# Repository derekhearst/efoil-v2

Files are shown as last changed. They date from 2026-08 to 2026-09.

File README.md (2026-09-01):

# eFoil V2

A DIY electric hydrofoil board, generated from a parametric Blender model that
also emits its own CNC drawings, cutting patterns, glass ply templates and
bill of materials. Change a parameter, re-run, and every downstream document
follows.

**V1 is built and riding.** V2 is the board this repo is about: a full model
with `FAILS: ['none']` on every check, a BOM where 131 of 135 purchasable
lines link to a real listing, and a machining plan that fits a specific
router in a specific shop.

---

## The one rule

**Nothing in `cnc/`, `print/`, `docs/bom.md` or `docs/shopping.md` is written
by hand.** They are generated from `model/*.py`. Editing them guarantees
drift, and drift in a cut list is a part you machine twice.

`model/report.json` is the contract between the scripts: `blender_board.py`
writes it, everything else reads it. `bom.py` refuses to run if it is stale.

---

## Regenerate everything

```bash
blender -b --factory-startup --python-expr "exec(open(r'C:/Users/derek/Development/eFoil/model/blender_board.py').read())"
```

That rewrites `model/efoil_v2.blend`, `model/efoil_v2_hull.stl` and
`model/report.json`, and prints the full check report. **If you have the
.blend open in the GUI, reopen it afterwards** — otherwise you are looking at
geometry that has already been fixed.

Then, in any order:

```bash
python model/cnc_drawings.py      # DXF part drawings + cnc/cut-list.md
python model/bom.py               # docs/bom.md + docs/shopping.md
python model/glass_templates.py   # developed glass ply outlines, DXF + printable HTML
```

```bash
blender -b --factory-startup --python model/print_miniature.py
```

Miniatures are exported at an explicit scale — scene units are metres and the
board is 1.4 units long, so a plain STL export reads as **1.4 mm** in a
slicer. Each file arrives at the size in its own filename.

### The build animation

```bash
blender -b model/efoil_v2.blend --python model/animate_build.py -- --res 1600
```

Two minutes covering the whole build in the order
[fabrication.md](docs/fabrication.md) gives it: glue-up, the CNC setups with
the router actually removing material, the flip, bonding, hardpoints, layup,
pack, module, install, deck pad, foil. Lands in `renders/build.mp4`, which is
**gitignored like the rest of `renders/`** — regenerate it, do not commit it.

Add `--stills` for one PNG per shot (about 15 seconds, and the way to check
choreography), `--shot NAME` for one shot, or `--dry` to print the shot list
and render nothing.

The router is not faked. Waste is built as
`slab − ((slab − part) ∩ swept)`, so the stock starts **solid** and the
finished surface is uncovered exactly where the tool has already been; the
cutter's Z is raycast against the real machined geometry rather than dropped
at a guessed height. Get that construction backwards — waste as `slab − part`,
which is the obvious one — and the finished planform is on screen before the
tool has touched anything.

---

## Layout

```
model/       the parametric model and every generator that reads it
cnc/         generated DXF drawings + cut list        (regenerate, never edit)
docs/        V2 documentation - see below
docs/v1/     V1 as-built, kept for reference only     (see "V1 archive")
print/       print-ready miniature STLs               (regenerate, never edit)
snapshots/   dated .blend captures of past shape decisions
```

Not in the repo: `renders/` (173 MB of build output) and `reference/`
(manufacturer marketing imagery used to fit the hull — not ours to
redistribute).

---

## V2 documentation

Four documents, three of them generated. Start with the build guide.

| Doc | What it covers |
|---|---|
| **[fabrication.md](docs/fabrication.md)** | **The build guide.** Every step in order, what blocks on what, what runs in parallel, and the exact BOM lines each step consumes |
| [cut-list.md](cnc/cut-list.md) | *Generated.* Every flat part, the four core pieces, the milling table, and the deck-pad cutting pattern |
| [bom.md](docs/bom.md) | *Generated.* Every line, linked to the listing its price came from, with per-line confidence |
| [shopping.md](docs/shopping.md) | *Generated.* The same spend grouped by supplier — the order you actually place orders in |
| [shape-research.md](docs/shape-research.md) | Traced production boards and the shape law fitted from them |

The build guide quotes BOM item names verbatim, and
`python model/check_build_guide.py` verifies every one still exists - and
now every bolded figure in this file and in the guide against `report.json`
and `bom_stats.json`. 133 of 135 purchasable lines are claimed by a step; the
rest are contingency tools.

---

## Key numbers

| | V1 (built) | V2 (current model) |
|---|---|---|
| Dimensions | 1600 × 600 × 153 mm | 1400 × 560 × 143.7 mm |
| Sealed displacement | 96.6 L | 79.0 L |
| Board mass | 25–30 kg | 23.6 kg |
| Board reserve, alone | — | +55.4 kg |
| With an 86 kg rider | — | **-30.6 kg — a sinker at rest** |
| Pack | 14S9P, 2,268 Wh | 16S8P, 2,304 Wh, 9.22 kg, 397 × 188 × 78 |
| Cavity | 660 × 280 × 115 mm | 512 × 323 × 86 mm |
| Electronics | 2 sealed boxes | 1 removable module: printed ASA walls on a 5052 floor, **outward** lid flange |
| Mast plate | — | 6061-**T651**, 12.7 mm, **M6** tapped, 1.44× margin |
| Hatch | — | 12 × M5 into captive nuts printed into an ASA rim ring |
| Core splits | — | vertical at 1030 mm (bed length), horizontal at 101.6 mm (gantry) |
| Machining | — | 4 pieces, 5 setups, 1 flip, no cradle |
| Deck pad | — | 3 pieces of 5.8 mm EVA, one sheet does both boards |
| Cost | ~$3,900 spent | **$4,046/board**, 90% verified |

The board is a **sinker** — 79.0 L will not float a rider standing still.
That is a consequence of narrowing to 560 mm, but note it has moved twice:
an earlier revision of this README claimed "+12.0 kg — it floats the rider"
from when displacement was 114 L, and the pack-height correction has since
given 5 kg of it back. If floating at rest matters to you, that is the number
to argue with.

---

## Open questions

Ordered by what can actually stop the build.

1. **Will the makerspace allow EPS — and cured fibreglass — on the CNC?**
   Unanswered, and it is now two materials on one phone call. It is a
   woodworking shop with no published material policy, and this is the one
   that can stop the booking outright. Maker Shop Boise, (208) 254-6151.
   EPS gates the core; **glass gates machining the two laminated lids**, and
   if the answer there is no, the MDF masters do them at home instead.
2. **Can the lids be laid up inside the CNC month?** The lids are machined on
   a *second* visit, which means the vacuum rig has to be working about three
   weeks earlier than the build order otherwise needs it. Eight visits are
   allowed in the month, so the visit is not the problem — the schedule is.
   If it slips: a **$99 day pass**, or the masters.
3. ~~**Cutter reach.**~~ **Closed.** The deepest pocket is the cavity's lower
   half at **71.6 mm** and the Freud O-flute cuts **31.8 mm**, which is where
   this question came from — but roughing never needed the reach (Z-level
   passes put the shank in open air) and the BOM has carried a **76.2 mm**
   wall-finish spiral for the one pass that does. The check was asking the
   roughing bit.
4. ~~**Wire bay stops at 68 mm.**~~ **Closed — it is 75.** The check that
   refused 75 was the in-build rim-segment volume test, the one later shown to
   report 53% of a ring that measures 99.96% in the saved file. It was
   measuring the booleans wrong, not the geometry. That test is demoted, and
   the bay is the 75 mm Derek asked for in the first place.
5. **Gong import duty.** Shipping is measured ($268.63 for two foils, from
   their checkout), but US customs is not. It arrives later as a courier
   invoice. Budget ~$210 if a 15% rate holds; the BOM carries it at zero so it
   is never mistaken for a verified figure.
6. ~~**Sinker at rest.**~~ **Closed — accepted.** 79 L will not float a
   rider standing still, and that is the board Derek wants.
7. ~~**V1's reed-switch kill system.**~~ **Closed — not doing it.** Derek's
   call on his own board. Worth recording what the item actually said: it was
   scoped *"required before any beginner rides that board"*, so it is about
   lending V1 out rather than about riding it himself. If someone else ever
   takes it out, this reopens.
8. **Measure the Gong top plate — thickness first, then its four clearance
   holes.** Two numbers, one part, and Derek already owns it (he cut its wire
   slot).

   **7a — the THICKNESS.** ~~Assumed at 20.0 mm.~~ **MEASURED: 12 mm, and
   countersunk.** That answered a question the model could not ask itself —
   `MAST_HEAD_T` had called itself *derived*, from `30 − INSERT_L`, which is
   our own tap depth, so it could only ever agree with us. The real number
   says **Gong's supplied M6 × 30 cannot be used**: a countersunk length is
   measured over the head, so it protrudes 18 mm below their plate against
   our 10 mm tap and **bottoms out by 8 mm** — torquing up tight with
   near-zero clamp on the joint carrying the whole rig.

   Not Gong's error. Those screws ship with **four M6 brass square nuts** —
   track hardware for a US box, where the length is meant to run past a plate
   and pick up a nut. We tap a plate instead, so their length was never ours.
   The board now buys **M6 × 22 A4-70 countersunk (DIN7991)**: 10 mm engaged,
   1.67 × D, 1.42× the bolt, 2.7 mm of blind alu. **The plate was right all
   along — the screws were wrong.** Still unmeasured on their part: the
   **countersink angle**, assumed 90°.

   **7b — the four clearance holes.** `MAST_CLEAR_D` is a guess at 7.0 mm and
   it sets the *entire* positional budget for our four tapped holes — at 7.0
   that budget is 0.25 mm, which is what makes it a machine-shop part rather
   than a drill-press one. A wider hole relaxes it; a tighter one may make it
   unbuildable by hand at all.
9. **Where the mast's wire slot sits relative to the chord.** `CONDUIT_X_OFF`
   is 0, i.e. the conduit is assumed to be on the mast's centreline, and that
   is unverified. If it is not, the conduit and the plate's Ø30.8 bore are in
   the wrong place — and that bore is drilled and reamed into the one part
   that has to go to a machine shop.
10. **`GUIDE_OFF` — the seal groove template's bushing offset.** Template 14's
   path is drawn **5.0 mm** outboard of the groove, which is
   `(bushing OD − cutter OD) / 2` for a bushing nobody has measured. It is
   the one number on that part that comes from the *tool* rather than the
   design, and if it is wrong the groove lands off by exactly the error — in
   the sealing land, on the joint that must not leak. **Measure it on the
   P601 before the template is cut.** It cannot come off the rotary tool: the
   TVM01 has no router base to mount a bushing to.
11. **The charge port's flange pitch, and whether a screw cap ships with it.**
   `CHG_BOLT_PITCH` is 22 mm on a two-hole SP17 flange, and no drawing has
   ever been found for it — the four-on-a-20-mm-square pattern belongs to the
   EW-LP16, a different connector. These holes go into a **printed** wall, so
   order the connector early and measure it before the module shell prints at
   step 3. The cap matters just as much: it is the entire reason this
   connector was chosen over the LP16's nicer one-touch latch, and Renhotec
   list SP17 sealing caps as *available*, which is not *included*.
12. ~~**The module vent is the next barrier down.**~~ **Closed for water.**
    It was a $9.95 no-name "IP68 nylon breather", and IP68 with no stated
    depth or duration is a marketing string, not a rating. Now a **GORE
    PolyVent Stainless, M12 × 1.5, 316L** — tested to IEC 60529 at 2 m for
    1 hour, IP69K to ISO 20653, salt fog, UL 94 VTM-0 membrane, laser-marked
    for traceability. Against the **62.2 mm** of head this cavity can ever
    put on it that is **32×**, so it goes from the module's weakest opening
    to its strongest. Sized on Gore's own table: 1.6 L/min covers a 20 L
    enclosure and the module has ~3.3 L of free air, 6× over.
13. ~~**Nothing relieves a cell venting.**~~ **Answered, and better than
    feared.** The vent is still not relief — it passes **1.6 L/min** against
    the ~12 a runaway cell wants — but the box was never a pressure vessel
    either. Both lids are hard-stop bolted joints, and a bolted joint
    separates, dumps and re-seats: the **module lets go at 0.81 bar**, the
    **hatch at 0.87**. Both are ~7× the 0.11 bar a hot box makes going into
    cold water, so neither opens in service, and both are far under anything
    that stores dangerous energy. It will not be pretty, but it blows through
    rather than building up. Which lid goes *first* is not knowable — 7%
    apart on two numbers that each carry ±25% preload scatter — so the check
    asserts a **ceiling** on both rather than an order it cannot measure.
14. ~~**Mast plate weight.**~~ **Closed — it is not overbuilt.** Asked three
    times, so here is the arithmetic rather than an opinion. It *looks* like
    a lot of aluminium because it is, but the two dimensions are set by two
    unrelated constraints and both sit within ~15% of their floor:
    - **Thickness** = thread + barrier, stacked with nothing between them.
      **10 mm** of engagement (M6 × 22 is the only standard length that suits
      this joint) plus a **2.0 mm** blind wall = **12.0 mm** floor, against
      12.7 in hand. The slack is **0.7 mm**, about 62 g — and cashing it
      means 12 mm metric 6061 sitting *exactly on* the blind-wall limit.
    - **Footprint** is not prying at all; it is the area feeding the mast's
      couple into the skins. **1.14 g** against a **1.0 g** floor (45° of
      bank, itself 2.8× V1's measured capacity). 225 × 150 was tried: 0.91 g,
      under.

    Both weight routes tried and refused. The plate stays 1/2 in × 250 × 175.
15. **The board trims nose-up on paper, and nothing was saying so.** The
    combined rider-plus-rig CG sits **84 mm** ahead of the front wing's
    centre of lift against a target band of 150–250 — **66 mm short**. The
    target was printed in the report one line under the number and the two
    were never compared. Not a build FAIL, deliberately: both inputs are
    admitted guesses (`FOIL_D` = 200 is unmeasured, `STANCE_AHEAD` = 20 is one
    forum post). But a miss is a miss. Levers, cheapest first: stance (free),
    `MAST_X` (moves the machined pocket), `FOIL_D` (measure it on the real
    Allvator before touching anything machined). `FOIL_D` was also two
    separate literals in two functions — one constant now.
16. ~~**The VX3 receiver is bought and not placed.**~~ **Closed — V1 answers
    it.** I had written an RF placement rule (floor is aluminium, pack is
    nickel strip, keep it high and clear). Derek's evidence beats the theory:
    V1 ran this receiver inside an enclosure with a **bolted aluminium lid**,
    under a plywood hatch, and it worked. V2's ASA walls and glass/foam lids
    are more transparent than that, not less. It is tiny; it goes wherever it
    is out of the way of the wiring.

---

## V1 archive

`docs/v1/` is **reference only** — the board that was built, what it measured,
and where it leaked. It informs V2 but does not describe it. Where the two
disagree, the model and the V2 docs above are correct.

Two of these are superseded V2 *planning* documents, kept because the
reasoning is useful and the conclusions are not: they predate the model and
their numbers no longer hold.

| Doc | |
|---|---|
| [efoil-1-board-design.md](docs/v1/efoil-1-board-design.md) | V1 as-built: XPS construction, hatch, and the leak history that drove V2's sealing |
| [efoil-2-electrical.md](docs/v1/efoil-2-electrical.md) | V1 pack, BMS, enclosures, wiring as built |
| [efoil-3-propulsion.md](docs/v1/efoil-3-propulsion.md) | Motor, ESC, foil, prop, and measured performance |
| [efoil-4-build-order.md](docs/v1/efoil-4-build-order.md) | V1 build phases and pack welding procedure |
| [efoil-7-vesc-config.md](docs/v1/efoil-7-vesc-config.md) | VESC settings, current limits, power diagnosis |
| [efoil-8-v2-planning.md](docs/v1/efoil-8-v2-planning.md) | *Superseded.* Early V2 direction and budget |
| [efoil-9-v2-board-design.md](docs/v1/efoil-9-v2-board-design.md) | *Superseded.* Early V2 spec — 150 mm thick, G10 module, different cavity |
| [shopping-list-v10.md](docs/v1/shopping-list-v10.md) | V1 spend reconciliation |

Numbering skips 5 and 6 — those were never written.

---

## Other scripts

| Script | |
|---|---|
| `model/templates.py` | MDF check gauges for hand-verifying the machined core |
| `model/performance.py` | Speed / thrust / runtime against V1's measured numbers |
| `model/price_check.py` | Re-checks BOM prices against recorded sources |
| `model/trace_reference.py` | Extracts planform, thickness and rocker from manufacturer orthos |
| `model/links.py` | *Generated.* item → (ASIN or URL, price, title) for every sourced line |
| `model/check_build_guide.py` | Verifies the build guide's BOM references still resolve |
| `model/check_rim_segments.py` | Measures the rim segments from the SAVED .blend — the in-build check is not reliable |
| `model/animate_build.py` | The build animation, above |

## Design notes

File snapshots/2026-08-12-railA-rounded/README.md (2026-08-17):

# Snapshot — rail "A", rounded, chine aft

Taken before applying the three research-driven changes (chine extent, rail
apex, bottom vee). This is the state Derek said he liked the look of.

## Hull shape
| param | value |
|---|---|
| LENGTH x WIDTH x THICK | 1400 x 600 x 144.9 |
| DECK_WIDTH_F | 0.72 |
| BOT_WIDTH_F | 0.88 |
| RAIL_APEX | 0.42  (rounded, mid-height apex) |
| BOTTOM_VEE / VEE_MAX_F | 16.0 / 0.12 |
| CHINE_HARD_X0 / X1 | 0.30 / 0.62 |
| CHINE_HARD_DEG / SOFT_DEG | 72 / 3 |
| N_TAIL / N_NOSE | 2.30 / 1.90 |

## Reported state
FAILS: none - interference: none
displacement 97.93 L - board 24.7 kg - rig 32.0 kg
net float -20.1 kg - deck 40 mm under
CG 47.1% from tail - cavity 527 x 306 x 89

## Restore
    cp snapshots/2026-08-12-railA-rounded/blender_board.py model/

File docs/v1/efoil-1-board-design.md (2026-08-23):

> **V1 reference — not the current design.** This describes the board that was
> built, or early planning that predates the model. V2 is generated from
> `model/blender_board.py`; where the two disagree, the model and the docs
> linked from the [README](../../README.md) are correct.

# eFoil Build — Board Design (V4)

**Last updated:** August 7, 2026 (as-built — hatch design changed from cam latches to bolt-down; leak history added)

## Overview
Single-cavity layout modeled on Gustav's Danish eFoil V2 build (foil.zone). Shared birch plywood base plate serves as both mast hardpoint and electronics floor. Board shape refined based on foil.zone community feedback: DutchFoiler (less bulky/brick-like), sat_be (sharp bottom edges at tail for takeoff), Kian (Flite-style board shape inspiration). Hatch uses strap hinges on the nose edge + a 6-bolt bolt-down lid (cam latches were designed but abandoned — see Hatch Design). Full CAD model in Onshape.

---

## Dimensions
1600mm × 600mm × 153mm (63" × 23.6" × 6").

**Volumes (from Onshape, post-CAD-finalization):**
- **Foam volume: 75.3L** (measured via mass properties, post-cavity-cut and post-chamfer/fillet). This is the material to buy and shape, and the buoyancy the board provides if the hatch leaks.
- **Cavity internal volume: ~21.3L** (660 × 280 × 115mm — cavity footprint through all 3 foam layers, depth from plywood base plate top to hatch lid underside).
- **Full sealed displacement: ~96.6L** (foam + sealed cavity air when hatch is closed and watertight). This is what matters for buoyancy during riding.

At 86 kg rider weight + ~96.6L sealed displacement, reserve buoyancy is ~10.6 kg — classic "sinker" board. Rider will not float above the waterline while standing on the board. Water start required (lie on board, knee up, stand up as speed builds). This is standard for performance eFoil builds.

> **CORRECTION — that +10.6 kg is wrong, and it is the number V2 has been
> compared against all along.** It is `96.6 − 86`: displacement minus rider,
> with the board's own 25–30 kg never subtracted. The board has to float
> itself before it floats anybody. The real figure is
> `96.6 − 86 − 27 = −16.4 kg`, which is why the same paragraph calls it a
> sinker — the word was right and the arithmetic was not.
>
> V1's foam volume checks out independently: measuring the Onshape STL in
> `stl/` gives **73.26 L** against the 75.3 L claimed here, and 73.3 + 21.3
> of cavity lands within 3% of the 96.6 L envelope. It is the buoyancy sum
> that was wrong, not the volume.
>
> Left in place rather than edited away because V2's targets were set from
> it. If V1 in fact floats a standing rider, then something else in these
> numbers is off — most likely the board's real mass — and the way to settle
> it is a bathroom scale, not more arithmetic.

---

## Exterior Shape

**Top-down outline (three-zone geometry, confirmed in Onshape):**

| Zone | Length (from tail) | Start width | End width | Rail arc |
|---|---|---|---|---|
| Tail taper | 0 → 400mm | 200mm (flat tail) | 600mm (full) | R500 concave (curves inward) |
| Parallel midsection | 400 → 1000mm | 600mm | 600mm | straight |
| Nose taper | 1000 → 1600mm | 600mm | 100mm (flat nose) | R845 concave (curves inward) |

- **Tail:** 200mm flat base at the very end. Rails curve inward via R500 concave arcs, tapering down from full 600mm width to the 200mm flat over 400mm of length. Same concave geometry as the nose, just with a tighter radius (R500 vs R845) over a shorter length (400mm vs 600mm) — the tighter/shorter taper is what gives the tail its blunter character compared to the more drawn-out nose.
- **Midsection:** 600mm of parallel 600mm width. This is where the rider stands and where the cavity sits.
- **Nose:** Rails curve inward via R845 concave arcs over 600mm of length, tapering down to a 100mm flat nose tip. The long, drawn-in nose taper gives the swept/eFoil-style profile (vs a symmetric elliptical "pill" shape).
- Tail is blunter and wider than the nose — nose is narrower (100mm vs 200mm) and taper is more gradual (600mm vs 400mm). Asymmetric in the classic eFoil way.
- **Edge treatment (4 operations, applied in CAD order — matches Onshape feature tree):**
  1. **Chamfer 1 — Top perimeter chamfer, 40mm × 60°**, tangent-propagated around the entire top edge (long rails + nose end + tail end, one continuous chamfer). In Onshape "Distance and angle" mode: 40mm measured along the deck face, 60° angle from deck, so the chamfer consumes 40mm of deck width and drops ~69mm of vertical rail height (40 × tan 60°). Creates the Flite-inspired wedge cross-section where the deck is significantly narrower than the hull footprint.
  2. **Fillet 1 — Nose rail rounding, R50**, applied to the two top-chamfer-to-side edges along the nose R845 arc region only, tangent propagation on. Softens the nose-rail corner where the deck chamfer meets the side face. Dies out naturally where the nose curve straightens into the parallel midsection.
  3. **Chamfer 2 — Nose tip bottom chamfer, 40mm × 60°** on the single edge where the nose vertical face meets the hull underside (at the bottom of the 23mm flat). Softens the front-bottom nose corner so the board doesn't stuff its nose on touchdowns after foiling — the first surface to contact water during a nose-down landing is a 60° ramp, not a sharp 90° corner. This is the ONLY chamfer or fillet anywhere on the bottom of the board.
  4. **Fillet 2 — Top perimeter soft edge, R20**, tangent-propagated around the entire top perimeter (both long rails + tail end + nose end + both Fillet 1 edges). Rounds the deck-to-chamfer corner everywhere. On the nose, it blends between the Fillet 1 R50 and the deck. On the straight rails and tail, it rounds what would otherwise be a sharp 90° deck-to-chamfer corner. Full-perimeter softening of the deck edge for rider comfort and clean visual lines.
- **Bottom edges stay sharp 90°** on all long rails, tail end, tail corners, and the bottom of the nose taper region. No bottom chamfer anywhere except the single Chamfer 2 at the nose tip. This preserves clean water release during takeoff (per sat_be's feedback about sharp bottom rails being essential at the tail).
- **Cross-section summary:** Flat bottom with sharp 90° bottom rails, flat side face, 40mm × 60° top chamfer rounded into the deck with R20 fillet, narrow flat deck. A truncated wedge — visually thicker at the hull and narrower at the deck, with soft deck edges and crisp bottom edges.
- **Nose bevel (side profile):** Bottom surface kicks up starting at 1000mm from tail (600mm from nose tip), sweeping upward along a **Rho 0.5 conic (parabolic) curve** that rises 130mm over the 600mm of length. The curve is tangent to the flat hull at its start (no kink — smooth transition) and reaches the 130mm rise at the nose tip. Board thickness at tip after bevel: 153mm − 130mm = **23mm flat vertical face at the nose tip**. Top of this face is rounded into the deck by the combined Chamfer 1 + Fillet 1 + Fillet 2 sequence. Bottom of this face is rounded into the hull underside by Chamfer 2. Top deck stays full length. This whole sequence keeps the nose from catching during takeoff planing and touchdowns.
- Flat bottom through the tail and midsection (from tail to 1000mm mark — 62.5% of board length).
- Flat deck — no crown. Simpler to build, EVA pad provides grip.
- Tail: flat bottom, sharp bottom edges for clean water release.

---

## 3-Layer Foam Construction
All internal cuts done on flat sheets with hand tools (box cutter, chisel, surform rasp) BEFORE gluing layers together. No jigsaw needed — all cavity and channel cuts are done while each layer is a flat slab on the workbench. Gustav used a hot wire cutter against 1:1 templates printed from Fusion 360 — if you can rig a hot wire (nichrome + power supply), it gives cleaner cuts on XPS. Otherwise, box cutter for straight lines, surform rasp + orbital sander for shaping.

**Board layout from tail to nose (all dimensions from tail):**

| Zone | Position (from tail) | Description |
|---|---|---|
| Tail | 0 - 300mm | Solid foam. Structural, takes impact during water re-entry. Rear foot zone. |
| Main cavity | 300 - 960mm | 660mm × 280mm footprint. Full through-cut on ALL three layers (same width). Shallow 3/4" recess in Layer 3 top face around opening for hatch lid to sit flush. 3/4" birch plywood base plate overlaps ~50mm under foam on all sides, epoxied into a shallow recess in Layer 1, flush with hull surface. Contains: sealed battery enclosure (forward), sealed ESC enclosure (mid, forward of mast bolts), IP68 connector housings, power button (on battery enclosure), water alarm. BMS and fuse mounted side by side in battery enclosure (BMS on edge). Mast bolts in rear section of plywood (bolt pattern centered at 400mm from tail). Wire pass-through hole for phase wires aligned with Gong top plate. |
| Nose | 960 - 1600mm | Solid foam. Buoyancy and structural. Bottom surface kicks up starting at 1000mm from tail. |

---

## Layer Details

**Layer 1 (Hull/Bottom, 2" / 51mm XPS):**
- Full through-cut for main cavity (660 × 280mm, starting 300mm from tail)
- Shallow 19mm recess around cavity opening for plywood base plate overlap — plywood extends ~50mm beyond cavity opening on all sides, bonding under the foam with epoxy
- Plywood epoxied into recess, flush with hull surface
- M6 bolt holes (6.5mm clearance) and wire pass-through hole drilled AFTER fiberglassing — use Gong V2 top plate as template
- Plywood IS the cavity floor — accessible from above when hatch is open

**Layer 2 (Middle, 2" / 51mm XPS):**
- Full through-cut for main cavity — same footprint as Layer 1 (660 × 280mm)
- This layer provides the cavity walls (51mm tall)
- Rounded corners on cavity cuts (easier to fiberglass, stronger)

**Layer 3 (Deck/Top, 2" / 51mm XPS):**
- Full through-cut for main cavity — SAME footprint as Layers 1-2
- Shallow recess (~3/4" deep) carved into top face around the cavity opening perimeter for hatch lid to sit flush: Trim-Lok X2897BT EPDM ribbed sponge seal (0.300" × 0.500") bonded to the recess floor (not the lid), compressed between recess floor and lid underside when latched
- Plywood backing blocks (80×45×19mm, cut from 3/4" birch plywood) epoxied to the recess ledge at 2 hinge locations (nose-side short edge). Blocks sit on the ledge outside the cavity wall, butting up against the lid edge. Centered at 60mm from each corner of the 280mm cavity width (146mm center-to-center). Provides solid screw-holding for hinge deck-side leaf — foam alone won't hold screws under repeated load.
- Reed switch pocket in deck foam behind cavity (~250mm from tail, in solid foam)

---

## Mast Hardpoint (Integrated into Cavity Floor)
- 3/4" birch plywood base plate spans entire cavity floor — mast bolts go through the REAR section, centered at 400mm from tail
- Bolt pattern: 90mm × 165mm rectangle, 4× M6 bolts (standard foil top plate spacing)
- Through-bolt mounting: M6 hex bolts insert from below through hull fiberglass + plywood, nyloc nuts tightened from inside cavity
- Clearance holes: 6.5mm diameter (standard M6 clearance), drilled through all
- No threaded inserts needed — just bolts and nuts, replaceable if stripped
- All holes drilled AFTER fiberglassing is complete — use Gong V2 top plate as template held against hull to mark exact positions, drill through fiberglass + plywood in one shot
- Seal bolt holes with marine sealant or gasket between Gong top plate and hull
- Battery enclosure sits on the FORWARD section of the same plywood plate
- ESC enclosure sits in the MID section, FORWARD of mast bolts (no longer sitting on bolt heads)

---

## Hatch Design — AS BUILT

**Changed from the original design.** Cam latches and PETG strike plates were designed but never used. The lid is a **bolt-down panel** with hinges retained on the nose edge for alignment and to stop the lid getting lost.

**Lid:**
- 3/4" birch plywood, **epoxy hot-coat only — the fiberglass layup was skipped.** The hot coat is therefore the sole water barrier on the lid; all edges and every penetration must stay sealed.
- Drops into the shallow 3/4" recess in Layer 3, flush with deck
- Perimeter edges beveled for clearance (the ledge opening shrank slightly when thickened epoxy was applied during leak repair). **Bevel the outer edge only — the flat underside sealing band stays untouched.**
- Bevel doubles as a lead-in so the lid slides onto the gasket instead of catching it

**Fasteners:**
- **6× M5 bolts** through the lid into **M5-0.8 hex-drive threaded inserts** set in the ledge blocking
- Insert spec: originally EZ-LOK 400-M5 (25/64" drill). **Switched to hex-drive inserts** (rivodeco M5-0.8 × 12 mm) — driven from the hex socket with a bit in a drill, which fixes both the "bolt seizes in the insert" problem and the vertical-alignment problem the bolt-driver method caused.
- Lid clearance holes: **7/32" (5.56 mm)**, drilled off the *installed* inserts so they can't drift
- **Fender washers under every bolt head.** The plywood lid crushed under bolt load before an insert pulled out — load spreading is required, not optional.
- Insert rims sealed after driving

**Hinges (nose-side short edge):**
- 2× Pyntrax 316 SS strap hinges (6" × 1.18"), centers 60 mm from each corner of the 280 mm cavity width (146 mm center-to-center)
- **Hinge knuckle must sit directly over the lid/board seam** so the lid closes parallel onto the gasket rather than pivoting into it
- **Printed PETG spacer under the deck-side leaf** to lift the hinge by roughly the gasket's compressed height. **Shim empirically with the gasket in place — do not use a calculated number.** An oversized spacer tilts the lid, which forces over-torquing at the free edge, which is what crushed the plywood and pulled an insert.
- Screws: #8 × 1" flat-head stainless (304 is fine for freshwater), piloted ~5/64", pilot holes epoxy-sealed, hand-driven

**Gasket:**
- Trim-Lok X2897BT EPDM ribbed sponge, 0.300" × 0.500", **ledge-mounted** (not on the lid) so water drains outward when opening
- Uncompressed 7.6 mm → target compressed ~4.6 mm (~40 % compression, top of the 25–40 % window)
- **Corners are mitred, not bent.** A solid extrusion buckles and twists around tight inside radii — four mitred segments with RTV-bonded butt joints lay flat. Joints never land on a corner or under a bolt.
- Poured-in-place silicone (2-part, ~$35 kit, Shore 20–30A) remains the fallback if the extrusion won't seal. Platinum-cure silicone can be inhibited by amine-cured epoxy — wash blush thoroughly first.
- A bead of 3M 4200 around the *outer* edge of the seal, bonding it to the epoxied ledge, closes the path where water travels **under** the gasket

**Pull loop:**
- Short flat nylon/polyester webbing loop, anchored under the two free-edge lid bolts (opposite the hinges), exiting through the seam gap in the traction pad
- Low profile — just enough to get a fingertip under

---

## Leak History and Repairs (Aug 2026)

Three water tests. Each found a different path. Worth keeping because the same failure modes will apply to V2.

**Test 1 — hatch leak, hinge geometry.**
Oversized hinge spacers tilted the lid so the gasket was crushed at the hinge and light at the free edge. Bolts were over-torqued trying to pull the proud edge down; the plywood crushed and one insert pulled out.
*Fix:* thinner spacers shimmed empirically, insert re-bedded in epoxy, fender washers under all bolt heads. **Epoxy held the insert where 4200 had not.**

**Test 2 — water through the laminate, not the gasket.**
The gasket sealed correctly. Water was entering through **unsealed fiberglass cut edges at the cavity ledge** and wicking through the XPS foam. Confirmed by pouring water on isolated sections of the ledge.
*Fix:* thickened epoxy (Cab-O-Sil) over the ledge edges at entry and exit points, plus everywhere with similar exposed edge.
*Lesson:* **cured laminate is not waterproof at a cut edge.** Exposed fibre ends wick. Every cut edge needs neat epoxy — this is cheap and would have prevented the whole episode.

**Test 3 — reduced but not eliminated.**
Remaining seepage traced no further with pour testing.
*Fix:* thickened epoxy over the entire cavity interior, 3M 4200 in the hinge screw holes (an unsealed penetration nobody had accounted for), and a Flex Seal Liquid coat over the cavity interior as a belt-and-suspenders membrane.
*Caveats on Flex Seal:* it does not bond to cured epoxy the way epoxy does, and it must be kept off the gasket land, bolt bores, and insert faces — a compressible layer at any clamping surface undoes the seal geometry.

**Validated separately:** with the lid off and the hull pushed under, no water entered through the mast penetration or wire holes. The mast gasket and wire pass-throughs are sound.

**Both enclosures held** — *through the August tests.* The ESC and battery boxes stayed dry through every test recorded above, including the sessions where the cavity flooded.

**Test 4 — the enclosures did NOT hold (Aug 2026, after this doc was written).**
The cavity flooded again and **water got into both the ESC and battery enclosures.** No gasket, gland or fastener path was identified. Derek's read is that **water seeped through the printed PETG wall itself**, and then sat trapped inside.

*Two candidate mechanisms, and the second now looks more likely:*

**(a) Porosity.** An FDM wall is extruded beads laid side by side, and the valleys between them form a connected path through it. More perimeters make the path longer, not closed — these ran four wall loops.

**(b) The enclosures were SUBMERGED.** This fits the record better. The August tests said "both enclosures held" when the cavity took shallow water; they failed once it flooded deeply. A gasket that shrugs off splash behaves very differently under 100 mm of standing head, and both enclosure lids used the same squashed-strip-with-no-hard-stop arrangement as the hatch. **On this reading the enclosures did not fail independently — they failed because the cavity did**, which makes the hatch the single thing worth fixing.

*Lesson: fix the cavity first.* The hatch is the barrier everything else sits behind, and V1's was **6 bolts at 313 mm pitch on an EPDM sponge strip squashed against a flat ledge, with strap hinges** — no groove, no hard stop, so squeeze depended entirely on how hard each of six bolts was done up, and Test 1 records exactly that going wrong. V2 is 12 bolts at 141 mm (bow goes as pitch⁴, so **25× less**), an O3 cord in a machined groove, and **no hinge at all**.

*Secondary lesson, still worth the twenty minutes:* **a printed enclosure is not a pressure boundary on its own.** It needs a continuous barrier applied to it — a brushed coat of neat epoxy on both faces, outside first, since stopping water entering the wall beats catching it once it is already travelling inside one. And it needs to be **proved before it is trusted**, not discovered by riding: seal it empty, pull a vacuum, watch the gauge, then repeat submerged so any path pulls water *in* where you can see it.

**Repair — 4 more hatch bolts (Aug 2026).**
Two at the upper corners and two at the midpoints of the long sides, taking the lid from **6 bolts to 10**. Each new hardpoint was made by **plugging with epoxy, then drilling undersized for a threaded insert** — the same principle V2 uses for its potted lid holes, and the right way to put a fastener into plywood or laminate.

*Effect:* pitch goes 313 mm → 188 mm, and bow between fasteners goes as pitch⁴, so this is a **7.7× reduction**. V2 is 141 mm for comparison, so V1 still bows about 3× more than V2 will.

*But the seals are not comparable, and it matters:* V1's EPDM sponge is 7.6 mm tall and compresses 25–50%, so it has **1.9–3.8 mm of travel**. V2's Ø3 cord at 20% squeeze has **0.60 mm**. In absolute terms V1's seal can swallow far more bow than V2's can — which says the bolt count was probably not the whole story on V1.

**Observed pattern (Derek, Aug 2026):** upper corners sitting slightly low or not reaching full compression; **the hinges applying compression** on their edge; **the long-side midpoints running long** — i.e. proud and under-compressed. That is the classic hinge-edge-over / free-edge-under signature, and it is exactly where the four new bolts went.

**Diagnose before modifying — use a witness.** Smear a thin film of grease, chalk or marker on the lid's sealing face, close and torque normally, then open. Where it transferred, the seal made contact; where it did not, it did not. That maps compression right round the perimeter in five minutes with no parts and no guessing, and it will tell you whether the four new bolts actually fixed the midpoints or just moved the light spot.

**A hard stop for V1 is possible without rebuilding anything:** a **spacer at each bolt**, landing on the ledge outboard of the seal. The ledge is 38 mm wide and the seal is 12.7, so there is **25 mm of spare ledge** to land on. The seal is 7.6 mm tall, so:

| Target compression | Lid bottoms at | Spacer |
|---|---|---|
| 25% | 5.7 mm | 5.7 mm |
| **30%** | **5.3 mm** | **5.3 mm** |
| 35% | 5.0 mm | 5.0 mm |

Build them from washer stacks and tune once — the same method already used to shim the hinges. What this buys is not less compression at the hinge, it is **permission to pull every other bolt down hard** without fear of crushing the hinge edge, which is precisely the "midpoints running long" complaint. It is a stop at the bolts only, so it does not force compression at midspan on its own — but with 10 bolts at 188 mm it does not need to.

**What is still unfixed on V1: the hinges.** Test 1 was a *tilt*, not a bow — oversized spacers held one edge proud and left the gasket light at the free edge. A tilt puts an edge out by millimetres, which is the order the sponge actually struggles with, and adding bolts does not straighten a lid that is being held crooked. **Worth checking the lid sits parallel before the next session, and worth telling Kev.**

*This supersedes the "layered defence worked as designed" conclusion above.* The layers were the same material with the same flaw — a printed box inside a glassed cavity is two barriers only if the printed one is actually a barrier.

---

## Exterior Shaping (after foam glue-up)

1. Cut outline from cardboard half-template using box cutter (score deeply, snap) or surform rasp to rough shape. Template geometry (half-width from centerline as a function of station-from-tail): **100mm flat tail** at station 0mm → R500 concave arc from 100mm half-width at the tail up to 300mm half-width (full board width) at station 400mm → straight 300mm half-width through the midsection (stations 400-1000mm) → R845 concave arc from 300mm half-width at station 1000mm down to **50mm flat nose** at station 1600mm. Both tapers are concave (arc centers outside the board outline, rail curves toward centerline). Tail taper is shorter and tighter (R500 over 400mm) and ends at a wider flat (200mm full-width); nose taper is more drawn-out (R845 over 600mm) and ends at a narrower flat (100mm full-width).
2. Shape nose bevel (side profile): from the 1000mm-from-tail station forward, carve the bottom surface upward along a Rho 0.5 parabolic curve that rises 130mm over the 600mm of length, ending at a 23mm-tall flat vertical face at the nose tip. The deck stays full length — only the hull shortens. **Template-assisted approach:** print a side-profile template (thin sheet with the target curve cut into one edge, half-width so it hugs the board centerline) and use it as a guide to check depth at multiple stations as you remove foam with the surform rasp. Alternatively, step-cut method: generate intermediate depth marks from the CAD at every 100mm station along the bevel (target rise from hull: ~2mm at 100mm, ~9mm at 200mm, ~22mm at 300mm, ~40mm at 400mm, ~64mm at 500mm, ~94mm at 600mm — Rho 0.5 approximation), carve to each mark, then fair the curve between marks with the orbital sander.
3. Shape edges — 4 operations, in CAD order:
   - **3a. Chamfer 1: Top perimeter chamfer (40mm × 60°).** Mark a line 40mm inboard from the deck edge all the way around the board with a sharpie. Mark a second line on the side face 69mm below the deck surface all the way around. Remove foam between the two lines with the surform rasp to create a continuous chamfer around the entire top perimeter. This is a large cut — expect a lot of foam dust. Check cross-section consistency with a printed profile template.
   - **3b. Fillet 1: Nose rail fillet (R50).** Round the two nose-region top chamfer-to-side-face corners with a 50mm radius, only along the R845 nose arc region. Hand-shape with coarse sandpaper wrapped around a curved block (tennis ball, sanding sponge, or a PVC pipe section of appropriate diameter). Precision not critical — shape by eye to match the CAD render. Start the fillet where the nose arc begins (1000mm from tail) and carry it smoothly to the nose tip. It should blend naturally, with no abrupt transition into the parallel-midsection rail.
   - **3c. Chamfer 2: Nose tip bottom chamfer (40mm × 60°).** At the bottom of the nose vertical face, where the 23mm flat meets the nose-bevel hull underside, take a 40mm × 60° chamfer. Mark 40mm up the nose vertical face from the bottom and 69mm (approx) back along the hull underside, remove material between the marks. This is a single edge only — stops where the nose bottom corner meets the nose rails on each side. Do NOT extend onto the long rails or the tail.
   - **3d. Fillet 2: Top perimeter R20 softening.** Round the entire top deck-to-chamfer corner with a 20mm radius, all the way around the perimeter — long rails, tail end, nose end, blending smoothly over the R50 Fillet 1 areas on the nose. This is a final smoothing pass after the top chamfer is cut. Use sandpaper wrapped around a 40mm-diameter dowel or similar curved block. All top edges should feel smoothly rounded — no sharp corners anywhere on the deck edge.
   - **Note: bottom edges stay sharp 90°** everywhere except the single Chamfer 2 at the nose tip. Do not round or chamfer the long bottom rails, tail bottom edge, or tail bottom corners. Sharp bottom edges are essential for clean water release during takeoff (per sat_be feedback).
4. Smooth everything with orbital sander, 80 grit → 120 grit. Fill any dings or voids with thickened epoxy.
5. Optional: use 3D-printed cross-section templates at key stations (tail, mid-body, bevel start, mid-bevel, nose) to check rail profile consistency while shaping. Most useful for the top 40×60° chamfer which benefits from a consistent angle along the whole length.

---

## Fiberglass Layup — No Vacuum Bag Method

**Technique:** Following Gustav's Danish V2 approach — one surface at a time, one layer at a time. This is more sessions but produces strong, clean results without vacuum bagging. Gustav's V2 uses 4 layers per side which he says is "plenty strong and will last forever."

**Key principles:**
- Fillet all inside corners with thickened epoxy BEFORE glassing (fiberglass won't conform to sharp inside corners without bridging/voids — the fillet gives it a smooth radius to follow)
- One layer at a time, full cure between layers
- Between each layer: wash amine blush with warm water + sponge → dry → sand 80-120 grit → wipe with IPA → next layer
- Drape dry cloth over surface and smooth into position before wetting out. Work from center outward to avoid wrinkles.
- TotalBoat 5:1 epoxy with SLOW hardener throughout (30+ min working time)

**Glassing sequence (each step = one session, cure overnight between):**

**Phase A — Internal Cavity (3-4 sessions)**

A1. Thicken epoxy with chopped fibers or colloidal silica. Trowel fillets into ALL inside corners of cavity and hatch recess area. Aim for ~10mm radius fillets. Epoxy plywood backing blocks (80×45×19mm offcuts) to recess ledge at 2 hinge locations on nose-side short edge, centered 60mm from each corner. Let cure.

A2. Glass cavity interior — 2 layers 6oz on floor (plywood) and walls. Drape cloth, wet out with epoxy. Use a plastic bag filled with water set inside the cavity to press cloth into corners and against walls while curing.

A3. Glass hatch recess area in Layer 3 — 3 layers 6oz for strength. This is the surface the gasket compresses against and where the hinge plywood blocks and lid threaded inserts land. Needs to be beefy. **Seal every cut edge here with neat epoxy** — unsealed laminate edges at this ledge were the source of the Test 2 leak.

A4. Seal any remaining internal surfaces with a coat of neat epoxy or one light layer of glass. Every internal surface must be waterproofed.

**Phase B — Hull / Bottom (4 sessions)**

B1. Layer 1 bottom — first layer 6oz. Drape cloth, smooth into position, wet out. Wrap cloth up and over the rails about 2-3" onto the sides.

B2. Layer 2 bottom — second layer 6oz. Same process, offset the cloth edge slightly from Layer 1 for stagger.

B3. Layer 3 bottom — third layer 6oz. Offset again.

B4. Layer 4 bottom — fourth layer 6oz. Final bottom layer. After cure, sand smooth 80→120 grit.

**Phase C — Deck / Top (4 sessions)**

C1. Layer 1 deck — first layer 6oz. Drape over the deck, wrapping down over the rails to overlap the cured bottom layup by 2-3". Sand the cured bottom rail overlap zone well before this step (80 grit + IPA wipe). Cut opening for hatch area — or glass over and cut open after cure.

C2. Layer 2 deck — second layer 6oz. Same process.

C3. Layer 3 deck — third layer 6oz.

C4. Layer 4 deck — fourth layer 6oz. After cure, sand smooth. The rails now have 8 layers total (4 bottom wrapping up + 4 deck wrapping down) — this is the strongest part of the board.

**Phase D — Hatch & Finishing (3-4 sessions)**

D2. Fabricate hatch lid — cut 3/4" birch plywood to fit the Layer 3 recess. Lay up 3-4 layers 6oz on one face, cure overnight, flip, 3-4 layers 6oz on the other face. Sand smooth. Seal edges with neat epoxy. Finish-sand the underside contact zone (38mm-wide perimeter ring that presses on the gasket) to 220 grit and apply one neat epoxy hot coat — smooth, glass-like surface for the gasket to compress against. **Do NOT bond gasket to lid** — gasket goes on the ledge in a later step (D5).

D3. Install 2× Pyntrax strap hinges on nose-side short edge — deck-side leaf into plywood-backed recess ledge, lid-side leaf into plywood lid. Add 3D printed shims as needed to tune gasket compression. Set M5 hex-drive inserts in the ledge blocking, then drill 7/32" lid clearance holes off the installed inserts.

D4. Open/clean hatch opening if glassed over. Clear mast bolt holes through fiberglass. Sand and prep all surfaces.

D5. Install hatch gasket on ledge. (Do this AFTER all paint/clear coat is fully cured — typically end of Phase E, but listed here with the rest of the hatch work for continuity. If paint hasn't happened yet, delay this step until after E4.) Surface prep: lightly scuff the 38mm-wide sealing ledge with 220 grit to kill the glossy epoxy/paint surface, wipe twice with IPA, let flash off completely. Peel PSA release liner from Trim-Lok X2897BT seal. Starting at the midpoint of a long straight edge (NOT a corner), press seal into position with firm finger pressure. Bend seal around inside corners — do NOT cut and butt-joint at corners (corner joints leak). Continue around perimeter until back at the start, cut to length with ~1mm compression fit, and close the loop with a butt joint at the starting midpoint. Put a tiny dab of thin cyanoacrylate on the two cut faces before butting them together to lock the joint. Apply silicone grease to the TOP surface of the seal (the side that contacts the lid) to prevent the compressed EPDM from bonding to the fiberglassed lid underside over long storage periods. **Leave hatch OPEN for 72 hours** for acrylic PSA to reach full cure before first compression. **Do not latch the hatch shut during this cure period.**

**Phase E — Finishing (3-4 sessions)**

E1. Epoxy hot coat — thin coat of neat epoxy over entire board to fill weave texture. Sand 120→220 grit.

E2. Spray filler primer (gray) — 2 coats. Sand 320→400 grit. Inspect for imperfections, fill and re-prime as needed.

E3. Lime green base coat — 3 coats spray paint. Light sand 400 grit between coats.

E4. Clear coat — 2-3 coats. Final wet sand 600-800 grit if desired for gloss, or leave satin.

E5. Apply traction pad. **As built:** one continuous pad across the whole deck including over the lid, cut into two pieces along the hatch seam (deck piece + lid piece) with a 1–2 mm relief gap so the lid still hinges. Cutouts at the 6 lid bolt positions for driver access, and a gap at the free edge for the pull loop to exit. Template on the deck, cut the foam on a bench (never over the paint), peel the PSA *after* cutting, and only stick it down once the clear coat is genuinely hard — days, not hours.

**Total glassing sessions: ~14-16 sessions over 3-4 weeks** (one session per evening, cure overnight, sand/prep next morning, glass next evening).

**Epoxy usage estimate:** 4 layers each side + cavity + hot coat + hatch lid ≈ 2.5-3 quart kits of TotalBoat 5:1. You have 2 ordered — will likely need a third.

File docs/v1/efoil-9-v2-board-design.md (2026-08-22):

> **Superseded planning document.** This predates the parametric model and its
> numbers no longer hold — thickness, module material and cavity size have all
> changed since. Kept because the reasoning is useful and the conclusions are
> not. See the [README](../../README.md) for the current design.

# eFoil V2 — Complete Board Design

**Created:** August 8, 2026
**Status:** Design spec. Build starts after a season of V1 riding data.
**Companion files:** `board_gen.py` (parametric hull generator), `blender_board.py`, `efoil_v2_hull.stl`, `efoil-8-v2-planning.md`

---

## 1. Design Philosophy

Every V1 failure traced to **hand-executed geometry being inconsistent**, not to bad design decisions. V2 attacks that directly with three changes:

| Change | What it removes |
|---|---|
| **CNC-milled core** | Hand-fillets, uneven cavity walls, out-of-plane gasket lands |
| **Grooved O-ring** | Compression tuning by feel — seal squash becomes a machined dimension |
| **Vacuum bagging** | Resin-ratio variability, and the weight that came with it |

**The difficulty moves from the build to the setup.** CAD, milling, and bagging prep get harder and more front-loaded. Assembly gets much easier and far more predictable.

---

## 2. Dimensions

| | V1 | **V2** | Δ |
|---|---|---|---|
| Length | 1600 mm | **1400 mm** | −200 |
| Width | 600 mm | **570 mm** | −30 |
| Thickness | 153 mm | **150 mm** | −3 |
| Volume | 96.6 L | **53.9 L** | −42.7 |
| Weight (est.) | 25–30 kg | **16–18 kg** | ~−10 |

Volume figure is from `board_gen.py`, calibrated against published Lift specs (model gives 1400 × 570 → 53.9 L; Lift 4'7 LIFTX is 1400 × 520 → 49 L).

### ⚠️ The volume trade-off — read before committing

**You cannot have short, narrow, thin, and high-volume.** Real shaped boards fill only ~45–47 % of their bounding box.

| L × W × T | Volume | vs V1 thickness |
|---|---|---|
| 1400 × 560 × 118 | 41.7 L | −35 mm |
| **1400 × 570 × 150** | **53.9 L** | **−3 mm** |
| 1400 × 560 × 180 | 63.6 L | +27 mm |
| 1500 × 600 × 145 | 59.9 L | −8 mm |

At 86 kg rider + ~17 kg board, 53.9 L is **−49 kg net** versus V1's −16 kg. Lift ships 49 L boards for *advanced* riders on 7.9 kg carbon hulls.

**If takeoffs prove difficult on V1 this season, build the 1500 × 600 × 145 (60 L) instead** — still thinner and shorter than V1, much closer to how Lift positions the Laird 5'2 for heavier riders.

### Planform / profile parameters
```
WIDE_POINT   0.48    (fraction of length from tail)
NOSE_PULL    1.75    TAIL_PULL    2.20
TAIL_WIDTH   0.84    NOSE_WIDTH   0.16
NOSE_ROCKER  78 mm   TAIL_ROCKER  6 mm    ROCKER_START 0.55
THICK_POINT  0.46    THICK_NOSE   0.30    THICK_TAIL   0.88
RAIL_HEIGHT  0.34    BOTTOM_FLAT  5.0     DECK_CROWN   3.0
```
Hard-ish chine rails (flat bottom turning sharply at the rail) for release on takeoff, per sat_be's V1 feedback.

---

## 3. Core Construction

### Material zones — dense material follows point loads, skins do the structural work

```
        ┌──────────────────────────────────────┐
        │           EPS ~2 lb/ft³              │  ← everywhere else
        │   ┌──────────────────────────────┐   │
        │   │  H200/H250 dense transition  │   │  ← ring, +80–100 mm beyond G10
        │   │      ┌──────────────┐        │   │
        │   │      │  G10 plate   │        │   │  ← bolts land here only
        │   │      └──────────────┘        │   │
        │   └──────────────────────────────┘   │
        └──────────────────────────────────────┘
```

**Taper or step-lap the density transitions.** A butt joint between H250 and 2 lb EPS is still a stiffness discontinuity — mill a chamfer on the mating faces so stiffness steps down gradually rather than falling off a cliff.

### CNC seam
- **Seam at 1000 mm from tail** → halves of 1000 mm and 400 mm
- Both under a 1219 mm (4×4) makerspace bed
- Deliberately clear of both the mast hardpoint and the cavity — put the joint where the loads aren't
- **No structural insert at the joint.** The core isn't carrying the load; skins are. A hard slug creates a stress riser and telegraphs through the finish. Butt-glue with thickened epoxy, clamped flat on a reference surface.
- Optional: dowels purely for alignment during glue-up, not structure
- A band of biax across the seam, under the main skins

---

## 4. Mast Hardpoint

The highest-load feature on the board. Four M6 bolts at 8–10 N·m against a gasket, plus mast bending under rider weight.

- **Position: 350 mm from tail** (scales V1's 400/1600 ratio) — verify against your actual wing's centre of lift
- **Single fixed bolt position** (per decision — no track box). Gong Allvator mounts on a fixed 4-bolt top plate, so a foil box buys nothing structurally and adds a large recess with more cut edges to seal.
- **G10 plate** sized to the Gong top-plate footprint plus margin for bolt heads and washers
- **H200/H250 dense ring** extending 80–100 mm beyond the G10 in every direction
- **Compression column** of the same dense foam running from the G10 hardpoint straight up to the deck skin

### Why the compression column matters
Mast bolts pull *up* against the hull; the rider stands *down* on the deck directly above. Without a column, the deck skin spans that load alone and the core between crushes over time — you get a dished deck and progressive loss of bolt preload, which shows up as a leaking mast gasket.

V1's 3/4" plywood plate did this job implicitly by being thick and stiff. Going to G10 + foam loses that, so **the column is what replaces it.**

- Column footprint at least as large as the G10, ideally slightly wider at the deck end
- Bonded to the G10 below and the deck skin above with thickened epoxy — continuous load path
- **Mill as one piece with the surrounding dense ring** rather than gluing in a separate block

### ⚠️ Clash check — resolve in CAD first
Confirm the compression column does not collide with the cavity floor. If it does, either shift the cavity forward or make the cavity floor itself the load path — the latter changes how the floor is built, so decide early.

---

## 5. Cavity

**No stringer** — it would dead-end at the cavity anyway. The cavity walls become the structural spine once skinned.

| Element | Material | Reasoning |
|---|---|---|
| **Ledge / rim** | **G10 ring, laminated in** | 6 hatch bolts and threaded inserts land here. This is exactly where V1 failed (plywood crushed, insert pulled). Foam of any density won't hold a threaded insert. |
| **Walls** | Normal EPS + **extra biax** | Stiffness comes from skins, not core density. Invest in glass, not heavy foam. |
| **Floor** | Depends on layout | If it sits above the mast hardpoint it's in the load path → dense core. If offset (as V1), it carries ~12 kg of battery over a large area → normal core is fine. |

**Every inside corner gets a generous milled radius.** Sharp inside corners in a high-stress region is precisely the combination that delaminated V1's deck.

**Starting dimensions (from V1, proven):** ~620 mm long × 300 mm wide. **Revisit after the pack decision** — a 16S pack changes cell count and therefore enclosure size.

---

## 6. Hatch Lid

V1's lid was 3/4" plywood with epoxy hot coat only and no glass — the hot coat was the sole water barrier on the wettest part of the board, and the plywood crushed under a bolt head.

**V2: glass skin / PVC foam core / glass skin sandwich**
- Core: **Divinycell H80, 10–12 mm**. Closed-cell, so a breach doesn't wick like plywood.
- Skins: glass both faces, **wrapped around the perimeter so no cut edge is ever exposed**
- **G10 pucks let into the core at each of the 6 bolt positions**, laminated in — this is what stops the crush-and-pull failure
- **Fender washers under every bolt head**, even with G10 pucks
- Perimeter bevel on the outer edge as a lead-in, so the lid slides onto the seal rather than catching it

**Stiffness matters as much as strength.** A lid that bows between bolts breaks gasket compression mid-span and no amount of gasket tuning fixes it. Sandwich stiffness comes from skin separation — 10–12 mm core with thin skins is far stiffer *and* lighter than solid material.

### ⚠️ Decide in CAD: flush vs. proud
- **Flush in a recess** (V1 style) looks better and the traction pad runs over cleanly, but recess depth and lid thickness must match precisely — and any epoxy buildup on the rim shrinks the opening. This is exactly what forced the V1 lid to be beveled after the leak repair.
- **Proud on top of the rim** is uglier but far more forgiving to build.

---

## 7. Sealing System

### Grooved O-ring — the single biggest reliability upgrade
Compression is set by **groove depth and O-ring cross-section**, not by feel. The lid bottoms laminate-to-laminate on the rim and the seal squashes to exactly the design amount, everywhere, every time.

- Machine the groove into the G10 rim — **the highest-value CNC operation in the entire build**
- Lid underside must be a true flat plane; machine or carefully fair it, don't accept whatever the bag gives
- **No hinge.** The hinge is what caused V1's tilt → over-torque → ply crush → insert pullout chain. Bolt-down with a tether so the lid can't be lost.

### Charge port + switch (removes the routine reason to ever open the board)
- **Charge port:** ~5 A, so trivially easy to seal — waterproof marine/industrial or magnetic connector. **The connector is the water barrier, not the door.** The board must stay watertight with the access door hanging open in the rain.
- **Magnetic switch:** reed or hall sensor **bonded behind the laminate**. Zero penetrations. Strictly better than any physical switch.
- Both behind a small spring-open weatherproof panel door

### Pressure vent
**Design the mounting boss even if you don't fit one initially.** A sealed air volume going from a hot deck to cold water sees real pressure differential acting on the weakest seal, and drives condensation. Five-minute retrofit if the boss exists; a redesign if it doesn't.

### Mast penetration
**Don't redesign what worked.** V1's neoprene gasket under the plate with undersized collar holes passed submersion testing. Carry it over unchanged.

### Non-negotiable rule
**Neat epoxy on every cut edge, always.** V1's leak came from unsealed laminate cut edges at the cavity ledge wicking into the foam. Costs nothing; prevents the entire failure mode.

---

## 8. Layup

**Method: hand wet layup + vacuum bag.** Not infusion — roughly 80 % of infusion's quality for ~40 % of the process risk, and it works with TotalBoat 5:1 rather than requiring special low-viscosity resin.

**Fabric: E-glass, not carbon.** Saves $300–500 and is far more forgiving. With a proper sandwich and bagging, glass is plenty stiff for a foil board.

### Schedule (starting point — sanity-check against foil.zone builds)
| Area | Layers |
|---|---|
| Hull | 2 × 6 oz + 1 × 1708 biax |
| Deck | 2 × 6 oz + 1 × 1708 biax |
| Cavity walls | +1 × 1708 biax |
| Mast hardpoint region | +2 × 1708 biax, staggered/stepped edges |
| Seam | biax band across the joint, under main skins |
| Rails | wrap continuous, no cut edges |

### Bagging
- **Moderate vacuum, 10–15 inHg** — enough to compact, gentle enough not to crush EPS. Conveniently sidesteps the core-crush problem that makes full-vacuum infusion tricky on foam.
- **One face per session, two sessions total.** All that face's layers wet-on-wet in a single bag if pot life allows; 2+2 if it feels rushed. Never both faces at once.
- **Cavity:** mill a **caul/plug from the same CAD file**, release-taped, so the bag presses cavity laminate against something solid. Otherwise the bag tents over the void and applies no pressure to the walls.
- Peel ply the whole layup — uniform matte surface with tooth, and it pulls excess resin
- Pleat the bag and use extra tacky tape at inside corners so it presses in rather than bridging

### ⚠️ Practice first
**Bag two or three flat scrap panels before touching the real board.** Bagging is easier to get *consistent* but not easier to get *right the first time* — it adds vacuum integrity, corner pleating, and a hard timing constraint (wet out, peel ply, breather, seal the bag, all before gel). Learn that on something disposable.

---

## 9. Finish

1. Peel ply → uniform matte with tooth
2. Fill/high-build coat **thick enough to sand flat without ever touching fibre** (sand into the glass and it's unrecoverable)
3. Wet sand 400 → 800 → 1200 → 2000 on a block
4. 2K automotive clear, or compound and polish

**Post-cure before finishing** so shrinkage happens before you make the surface perfect, not after.

**Paint lessons from V1:** respect the recoat window absolutely — within ~1 hour or after full cure, never the 1–24 hour dead zone. Thin coats, sweep past the edges, never linger on a rail. V1's tail wrinkled because clear went onto color that had only cured 48 hours in 100 °F heat.

---

## 10. Build Sequence

1. **CAD everything first** — hull, cavity, hardpoint pockets, compression column, O-ring groove, all penetrations. Resolve the column/cavity clash.
2. **Confirm makerspace CNC bed size and whether they allow EPS** — this is a hard design constraint
3. Mill core halves, cavity plug/caul, G10 parts
4. Bond core halves flat on a reference surface
5. Bond in G10 hardpoints, dense-foam ring, compression column; fair flush
6. **Seal all cut edges with neat epoxy**
7. Practice-bag scrap panels
8. Bag hull skin (with cavity plug in place)
9. Flip, bag deck skin
10. Cut cavity opening; **seal every cut edge**; glass cavity walls (hand-consolidated)
11. Machine the O-ring groove in the G10 rim
12. Build the lid panel separately; machine flat; laminate G10 pucks
13. Set threaded inserts in the G10 rim
14. Fill coat → sand → clear
15. Fit charge port, magnetic switch, vent boss
16. **Submersion test, sealed and EMPTY, before any electronics go in**
17. Traction pad last, after clear is genuinely hard

---

## 11. Open Questions

- **Volume:** 53.9 L or the 60 L option? Decide after a season on V1 — if takeoffs are hard, go bigger.
- **Makerspace CNC:** actual bed dimensions, and do they allow foam?
- **Pack architecture:** 14S vs 16S+ determines cell count, enclosure size, and therefore cavity dimensions
- **Cavity floor:** in the mast load path or not? Determines whether it needs dense core
- **Wing centre of lift:** verify 350 mm mast position against the wing you'll actually run most
- **Lid flush vs proud**

---

## 12. What This Fixes

| V1 problem | V2 solution |
|---|---|
| Water wicked through unsealed laminate cut edges | Neat epoxy on every cut edge, always |
| Delamination at sharp inside corners | CNC-milled radii |
| Hinge tilt → over-torque → ply crush → insert pullout | No hinge; bolt-down with grooved O-ring |
| Threaded inserts pulled out of plywood | G10 hardpoints laminated in during layup |
| Uneven gasket compression | Groove depth sets compression, not feel |
| Resin-rich, heavy | Vacuum-bagged, ~10 kg lighter |
| Lid flexed and had no glass | Sandwich panel with G10 bolt pucks |
| Deck could dish over the mast | Dense-foam compression column |
| Had to open the hatch to charge | Charge port + magnetic switch behind an access door |

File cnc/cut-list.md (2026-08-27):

# CNC Cut List — eFoil V2

Generated by `model/cnc_drawings.py` from `blender_board.py`. Rerun after any parameter change.

Board 1400 x 560 x 143.7 mm · cavity 512 x 323 x 99 mm

## Flat parts

| # | Part | Material | Thick | Qty | Size (mm) | Notes |
|---|---|---|---|---|---|---|
| 1 | `01_rim_ring.dxf` | printed ASA (reference only) | 12.7 | 1 | 580 x 391 | 12 x CAPTIVE M5 NUT on a O18 penny washer, printed around at a pause - the small circle is the O5.6 bolt through-hole, the large one the washer pocket. This line used to read 'M5 STI tapped for stainless wire-thread inserts' and drew the holes at O6.4, an STI tap drill - that was the FIRST of three designs (G10 + wire-thread, then printed ASA + heat-set, now printed ASA + captive nut) and the rest of this very note already described the third. The nut is STEEL and never wears, which is what a hatch opened every ride wants. PRINT IT HOT AND PRINT THE NUT ZONE SOLID. What holds a captive nut in is a plug of ASA 4 mm deep sheared out around the washer, and that shear surface is a VERTICAL cylinder - with the ring printed seal-face-down its layers lie across it, so the tear runs through bead-to-bead and layer-to-layer interfaces the whole way and never through solid material. At a bulk 30 MPa that is 7.1x the 1.2 Nm spec; at a cold-print 20 it is 4.7x, and 1.1x against the 5 Nm a hand on a hex key reaches by accident. Chamber hot, no draughts, 100% infill for at least 10 mm around every nut pocket - that margin is a print-quality number, not a geometry one. ASSEMBLED REFERENCE ONLY - DO NOT CUT THIS OUTLINE, AND DO NOT CUT IT FROM ANYTHING. This note used to say 'cut parts 01a and 01b and bond them into this', which was an instruction to make two parts THAT DO NOT EXIST - they were the G10 ring bars, and they went when the ring became PRINTED. There is no sheet stock behind this drawing. The ring is 6 dovetailed ASA pieces printed from the V2_RimSeg_* solids in the .blend, and this outline is here only to check the assembled ring against the rebate and to carry the bolt pattern and CHANNEL reference. THE CHANNEL IS NOT MACHINED AT ALL, and not at this stage either: the groove is PRINTED into the ring 1.8 deep and filled with a strip printed 0.0 PROUD of the seal face, so the glass drapes over a ridge you can see and feel. Sanding that face flat - which you have to do anyway, it is the seal land - breaks through to the filler and it picks out, leaving 4 wide x 2.4 deep finished for an O3 cord BONDED in. Part 14 is the routing template for anyone who would rather cut it, and it is a FALLBACK. Break the INNER top edge to R3 - the laminate turns over it into the cavity. Leave the outer edge and the bottom face SQUARE. |
| 2 | `01c_handle_strip.dxf` | 6061-T651 aluminium | 12.7 | 2 | 193 x 22 | TWO PER BOARD, port and starboard. Takes the two M6 strap inserts. Beds into a shallow (~1.6 mm) milled facet on the rail so the laminate lies over it - there is NO handle pocket. Nests in the offcut of the 1/2in sheet the rim ring comes from. |
| 3 | `02_hatch_lid.dxf` | glass/H80/glass 15mm | 15.2 | 1 | 577 x 388 | Bag oversize flat, then machine to this profile. Face the underside flat in the same setup - it is the sealing face and it lands hard on the rim ring, so it must be flat. DRILL ALL 12 O5.6 IN THIS SETUP, right through. Under each one is a O16.000 G10 plug already cast into the core, full depth, so the bit passes skin / resin / skin in one pass. Nothing to pocket, nothing to pot here, nothing to re-find afterwards. CUTTING THEM ALL HERE IS THE POINT: twelve holes bored in one setup are mutually accurate to the machine, so lining the lid up on the ring is a single rigid-body fit - get two to pick up and the rest already are. WHY THE PLUG IS THERE: this is a cored sandwich, and V1's lid was solid plywood so it never had this problem. At 1200 N a bolt - the PRELOAD at 1.2 Nm, not the 182 N the cord needs - a bare M5 cap head puts about 2.7 MPa into H100 even after the skin spreads it, against a core that crushes at 2.0. On the epoxy plug, on a O18 penny washer, the same bolt sits at 7.9 MPa against epoxy's ~50 and the foam carries none of it. THE WASHER IS NOT DECORATION - a bare cap head on resin is 37 MPa, and epoxy cold-flows under permanent preload. NO COUNTERSINK: the cone wants 2.1 mm of solid material and there is 1.0 mm of skin over the plug. Cap heads, proud, as intended. AND SEAL EVERY CUT EDGE WITH NEAT EPOXY - machined perimeter and the inside of all 12 bores. THAT part is V1's Test 2 verbatim: water wicking in through unsealed fibre ends at the cavity ledge. |
| 4 | `03_hatch_lid_core.dxf` | Divinycell H100 (2 x 1/4in bonded - no 1/2in H100 exists) | 12.7 | 1 | 589 x 400 | OVERSIZE BY 6 mm ALL ROUND, not inset. This drawing used to say 'inset 2 mm so the skins wrap the edge', which contradicted the lid itself - 02 says bag oversize and machine to profile, and machining to profile cuts the wrap off. You cannot do both. Machining wins, so the core is cut oversize with the skins and the profile goes through all three at once; step 12's neat-epoxy edge seal is what protects the exposed core. It also buys the plug its edge distance: the bolt circle ends up 10.5 mm from the FINISHED edge, so a O16.000 plug clears it by 2.5 mm. THE 12 CIRCLES ARE THROUGH-HOLES THAT GET FILLED WITH THICKENED EPOXY - O16, the hatch lid's hardpoints. Do it NOW, while this is a bare sheet on the bench with no skins on it: tape one face, pour, cure, sand BOTH faces flush. That is the whole reason it happens at this stage rather than after layup - no pocket milled to depth, no bolt hole filled in and re-drilled, and nothing to find under a cured skin later. A plug left proud prints through a 1 mm skin under vacuum: twelve bumps in the deck. |
| 5 | `04_module_floor.dxf` | 5052 aluminium | 3.2 | 1 | 427 x 298 | 1/8in 5052, NOT G10. One 12x24 sheet is one floor, so a 2-pack does both boards. Chosen for the ESC as much as the price: the ESC sits sealed in with 128 cells and no airflow, and G10 conducts 500x worse than aluminium - this floor is its heat spreader and thermal mass, the same job V1's alu bottom plate did. Costs +355 g a board, taken deliberately. NO GROOVE and no through-holes: bandsaw or jigsaw the rectangle and deburr, that is the whole part. The CHANNEL rectangle is a SCRIBE LINE showing where the wall foot lands - do not cut it. BONDING: abrade, solvent wipe and PRIME the aluminium, scuff the ASA, and hold a 2 mm bond line on beads or shim wire. Structural polyurethane, never epoxy - ASA and 5052 differ by 66 um/m/K, so a rigid line sees ~300% shear strain across a hot afternoon. Fillet inside AND outside onto the 3 mm ledge. |
| 6 | `10_module_lid.dxf` | glass/H80/glass 8.3mm | 8.3 | 1 | 443 x 314 | 18 x O5.0 M4 clearance. O5.0 not O4.5: the rails are drilled FLAT and then bonded up as a four-piece ring, so the ring's hole positions carry whatever the bond-up drifted. O4.5 leaves 0.25 mm radial and will bind. O5.0 leaves 0.5 mm, which the floor-as-master bond sequence holds. EVERY HOLE IS POTTED, AND THE PLUGS ARE CAST INTO THE CORE (11) BEFORE LAYUP - not pocketed into the finished panel afterwards. That was the instruction here and it is the same mistake the hatch lid was moved away from: 'drill through the top skin and core ONLY, leave the bottom skin' is a DEPTH-CONTROLLED cut into a bagged laminate whose thickness varies, and going 0.5 mm deep breaches the sealing face of the lid. Bore the bare core, fill, sand flush, then lay up - see 11. WHY IT NEEDS THEM AT ALL: this is a cored panel: at 625 N a bolt an M4 washer puts ~15 MPa on the seat and H-80 crushes at 1.4, so bare holes lose seal squeeze the first time it is torqued. The washer then bears on solid epoxy - ~4.4x margin. |
| 7 | `11_module_lid_core.dxf` | Divinycell H80 | 6.3 | 1 | 455 x 326 | THE 18 CIRCLES ARE O12 THROUGH-HOLES THAT GET FILLED WITH THICKENED EPOXY, and they are done NOW, while this is a bare sheet on the bench: tape one face, pour, cure, sand BOTH faces flush, then lay the lid up over it. Exactly what 03 does for the hatch. The alternative - pocketing them into the finished panel - is a depth-controlled cut into a bagged laminate whose thickness varies, and 0.5 mm too deep breaches the lid's sealing face. OVERSIZE BY 6 mm ALL ROUND, NOT INSET. This drawing used to say 'inset 2 mm for skin wrap', which is the same contradiction 03 already had and which was fixed there and never carried across: step 11a trims this lid TO NET PROFILE AFTER CURE, and machining to profile cuts the wrap off. You cannot do both. Machining wins here for the same reason it wins on the hatch - the profile and the 18 bolt holes want to be one setup, because their positions have to match a bonded-up printed ring - and step 12's neat-epoxy edge seal is what protects the exposed core. EDGE DISTANCE, and it is worth knowing what set it: the bolts sit 8.0 mm from the FINISHED edge, so a O12 plug reaches to within 2.0 mm of it - and so does the 12 mm washer that sits on top of it. Those two are the same constraint and they are why the bolt circle is where it is: one turn earlier it sat 1.5 mm further out, which left both of them 0.5 mm from the edge with a profile pass still to come. |
| 8 | `16_module_lid_guide.dxf` | MDF 12 mm | 12.0 | 1 | 443 x 314 | 18 x O5.0 bushings on the module lid pattern. THIS DRILLS THE HOLES. The CNC cuts lid 10's PROFILE only, registered by touching off on two black plugs - then this drops onto that finished profile, which it IS, and self-locates. Profile is registered to the plugs, this is registered to the profile, so the holes are registered to the plugs without anyone aiming at something buried. MARK WHICH WAY ROUND IT GOES: a rounded rectangle drops on equally well at 180 deg and the bolt pattern will not tell you. drilling 18 holes dead-centre through 18 plugs you cannot see is a job nobody should be asked to do, and doing it while the cured plugs are sitting there as black discs in white foam is trivial. Order: bore O12, pour BLACK-pigmented epoxy, cure, sand flush, drill O5.0 through each plug with this guide, fill the holes with black wax, THEN lay up. Afterwards the wax reads through the 1 mm skin and all that is left is opening 1 mm of glass over a mark that is exactly the hole - not 8 mm of sandwich aimed at a guess. REGISTER THE PROFILE CUT ON THOSE MARKS TOO. The holes must line up with the rails' printed inserts; the profile only has to fit a recess with 1.5 mm of clearance. So put the tolerance where the slack is - cut the profile relative to the holes, not the holes relative to the profile. IT IS THE LID'S EXACT FINISHED PROFILE, so it is also the thing you trim the laminate against - bearing-guided flush cutter, bearing on the MDF. Holes and outline then come off ONE physical part and alignment stops being a tolerance at all. It does NOT drill the rails: those bores are MODELLED and printed, so the inserts melt into full printed walls instead of into cut infill. NOT interchangeable with template 14 - that is 12 holes on a 580 x 391 ring, this is 18 on 443 x 314. |
| 9 | `17_hatch_lid_master.dxf` | MDF 12 mm | 12.0 | 1 | 577 x 388 | THE LID'S EXACT FINISHED PROFILE plus its 12 holes - one physical part carrying both. THIS DRILLS THE HOLES. The CNC cuts 02's PROFILE only, registered by touching off on two black plugs; this then drops onto that finished profile, which it IS, and self-locates - so the holes end up over the plugs without anyone aiming at something buried. MARK WHICH WAY ROUND IT GOES: a rounded rectangle drops on equally well at 180 deg. IT IS ALSO THE FALLBACK if the shop will not run cured glass or the layup misses the CNC month - then it does both jobs: on the BARE CORE before layup, drill the 12 x O5.6 through the cured black plugs, which is easy while they are still visible. After layup: register on the wax marks and trim the laminate to this outline with a bearing-guided flush cutter, bearing riding the MDF. Cut from the same numbers as 02_hatch_lid and 14_groove_guide, so master, lid, ring and captive nuts are one pattern in four places. NOTE it is NOT template 14: that one is the RING at 580 x 391 and carries the seal groove. This is the LID at 577 x 388. Label them. |
| 10 | `12_mast_plate.dxf` | 6061-T651 aluminium | 12.7 | 1 | 250 x 175 | 1/2in 6061-T651, NOT 3/4in G10, and NOT bushed. 4 x M6 TAPPED 10 mm BLIND from the PAD FACE (the wetted underside), leaving 2.7 mm of solid aluminium above so the plate stays watertight. Tap drill 6.8 mm. CONDUIT: ONE STRAIGHT O30.8 BORE on centre, right through. No step, no counterbore - an earlier version had both and neither was needed: the wire bung's stop is the epoxy liner's end face where the foam channel steps down to O22, and that is there anyway. REAM OR BORE IT, do not leave it drilled - the bung is a O30.0 disc that fills this hole top to bottom and hangs 0.000 mm below the wetted face, and the GONG MAST'S OWN PLATE squeezes that out as its four bolts pull it face to face with the board. This wall is what the rubber seals against. *** MACHINE THIS ONE. DO NOT HAND-DRILL IT. *** An earlier version of this note called it bandsaw and drill-press work. That was wrong, and it was wrong because it reasoned from V1 - where the holes were THROUGH holes, a nut landed on the far side, and clearance quietly absorbed every error of position, angle and depth. None of that is true here. These are BLIND TAPPED holes: the thread IS the fastener, nothing absorbs anything, and all four bolts have to start at once. The budget, in numbers: Gong's clearance hole gives -0.50 mm of radial slop, so true position has to hold about -0.25 mm across the pattern (errors at opposite corners do not cancel, they add). A hole drilled just 2 degrees off wanders 0.35 mm over its 10 mm depth - MORE THAN THE WHOLE BUDGET, on its own, and a hand-held drill is routinely 3-5 degrees off. Depth is no kinder: 2.7 mm of solid aluminium is all that stands between the tap and a hole through the plate that keeps the cavity dry. ORDER OF OPERATIONS THAT MATTERS: measure the REAL Gong plate first and machine to what you measured, not to the 165 x 90 nominal in this drawing - that figure is UNVERIFIED layout only, and a perfectly machined plate on the wrong pattern is still scrap. Route, in order of preference: (1) job-shop it - a 250 x 175 rectangle with four tapped holes is a trivial job and cheap against the cost of getting it wrong; (2) the makerspace CNC, IF they permit aluminium - it is a woodworking shop, so ask; (3) drill press with a bought drill bushing and a tapping guide, depth stop set - acceptable, but it is the fallback, not the plan. KEEP A THREAD REPAIR KIT ON THE BENCH either way: an M6 Time-Sert or helicoil turns a stripped or wandering hole into a ten-minute fix instead of a scrapped plate and a lost weekend. 6061 shears at ~207 MPa against G10's ~55, so the tapped thread (136 mm2, 17.7 kN) beats the O20 bonded bushing it replaced and the M6 bolt Gong supplies becomes the weak link - which is where you want it, but see mast_bolt_margin: it is 1.44x, not the 2.6 this drawing used to imply on an M8 that does not exist. TEF-GEL EVERY BOLT: aluminium plate, A4 stainless bolts, wet cavity. That is the whole galvanic mitigation and it is not optional. Nest both plates on one 12x18 sheet: 2 x 6.89in of the 18in length, 4.2in spare. |
| 11 | `13_cavity_caul.dxf` | EPS offcut | 85.8 | 1 | 511 x 322 | CUT IT TO FIT WITH THE RIM RING ALREADY IN PLACE. The ring is not bonded on after glassing - it is GLASSED IN during this same layup, sitting on its ledge with the printed filler strip waxed into its groove, and the laminate runs up the cavity wall, across the ledge and over the ring in one piece. So the caul has to drop inside the ring's inner edge and bear on the cavity, and it has to be the full depth to the ledge or the corner it exists to consolidate is the one corner it misses. Trial-fit it dry, with the ring in, before there is resin anywhere. EPS, not MDF - it only has to transmit bag pressure, and at 7 inHg that is 24 kPa against EPS's 150 kPa crush, 6x, deflecting 0.2 mm over its 90 mm depth. MDF was over-specifying a pusher. BEST CASE IT IS FREE: if the CNC PROFILES the cavity rather than pocketing it to chips, the plug that drops out IS this part, already the right shape - just skim it undersize. Release-taped or waxed. Supports the deck skin during bagging, then presses the cavity laminate into the corners. 0.5 mm under size per side. Break its own edges to the cavity's R10 or it will not seat. |
| 12 | `14_groove_guide.dxf` | MDF 12 mm | 12.0 | 1 | 580 x 391 | CUT THIS - it is the plan, not the fallback, and it used to say the opposite. The old scheme printed the groove filler 0.5 mm PROUD so the glass draped over a ridge you could sand down to. Self-finding, and it put a 0.5 mm step running 1.8 m along the SEALING LAND: glass over a step bridges at the two inside corners, so it seeded a pair of void-prone lines either side of the groove, in the one band of laminate the cord has to land on - and sanding back to the ring face lands about AT those corners rather than safely past them. The filler is FLUSH now and this template opens the groove - AND FINDS THE 12 BOLT HOLES IN THE RING - the RING, not either lid. Both lids get their holes from the CNC in the same setup as their profile and do not need this; the ring is the only part whose holes end up BURIED, because it is the only one glassed over. Those 12 circles are nonetheless the same bolt ring that cuts 02_hatch_lid, so template, lid and captive nuts come off ONE master and cannot disagree - and if the machine ever falls through for the laminated lids, this drills 02 as well. It will NOT do the MODULE lid: different count, different rectangle, and that one needs no template either - its rails are drilled FLAT before bond-up and the lid's O5.0 clearance is sized to swallow whatever the bond-up drifted. The holes are blocked during layup with COLOURED WAX, which keeps resin out of the nut pockets and shows through the thin laminate afterwards - line the template up on the two or three you can see clearly and the rest are right by construction. NO PRINTED MARKS ON THE RING FACE, proud or recessed: this face is the sealing land and the one rule it has is that nothing stands on it. Keep the wax INSIDE the hole and wipe the face before layup - wax on the land is a bond-line contaminant under the washer. LOCATE IT OFF THE REBATE WALL, which is 34 mm of CNC ledge with a vertical wall running the whole perimeter - true by construction, and continuous round the corners where a straight fence could not follow. Opens the seal groove AFTER glassing. Use a 2.5 mm cutter in the 4 mm groove - 0.75 mm of lateral slop each side before it can touch the sealing land. Set depth to just break into the filler; you will feel it go soft. Then pick the filler out and the PRINTED walls are the finished groove. THEN WET THE GROOVE OUT WITH NEAT EPOXY and let it cure before the cord goes in. Routing through the laminate leaves cut glass fibre ends in the groove's top edge, in the seal itself - the same path that flooded V1's cavity. Silicone adhesive does not stop a wick; epoxy does. Opening offset 5 mm for a guide bushing - RE-CHECK against your own. The CHANNEL outline is the rim ring's outer edge, for registering. |
| 13 | `15_deck_pad_nest.dxf` | EVA sheet 2400 x 600 | 5.8 | 1 | 2400 x 600 | CUTTING PATTERN, not a machined part - knife and a straightedge. 3 pieces for ONE BOARD, using 34% of the roll: one aft of the hatch, one forward of it, one on the lid. NOT PANELLED - seams land where you stand and every seam is an edge that lifts and packs with grit. Three pieces only because the hatch occupies the middle 600 mm and there is no continuous path past it. NOTHING RUNS UP THE SIDES of the hatch: those 27 mm slivers were outboard of the lid pad and bought four more lifting edges for nothing. ALL CORNERS RADIUSED 45 mm (lid 30 mm, matching the lid itself). A square corner on 5.8 mm self-adhesive sheet is the first place it peels and a snag underfoot besides. WIDTHS ARE DEVELOPED - the arc across the crown, not the flat shadow, which runs ~8.6% short. The outline is bisected to the 30 deg slope limit rather than stepped to it; stepping quantises the cut line to a visible staircase. That slope limit is what keeps the pad ON TOP - about 55 mm of bare rail, which is where the top of this board ends, not a shy margin. Lid piece inset 25 mm so the 12 M5 bolt heads stay exposed. CUT LONG AND TRIM ON THE BOARD, working from the centreline out. The CHANNEL outline is the sheet edge. |

## Stock

| Part | Size (mm) | Smallest sheet that holds it |
|---|---|---|
| `02_hatch_lid` | 577 x 388 | 24 x 36 in |
| `10_module_lid` | 443 x 314 | 24 x 36 in |
| `11_module_lid_core` | 455 x 326 | 24 x 36 in |

## DXF layers

| Layer | Meaning |
|---|---|
| `CUT` | through profile |
| `HOLES` | drill / bore, diameter as drawn |
| `CHANNEL` | placement line for the gasket lane — not a cut |

## EPS core — FOUR pieces, two splits

The core is cut in **four** pieces, not two, because it is bounded on two different axes:

| Split | Why | Number |
|---|---|---|
| Vertical at x = 1030 | bed is 1210 mm long, board is 1400 | 1030 + 370 |
| Horizontal at z = 101.6 | gantry is 149.9 mm, GLUED STACK is 203.2 | 2 layers + 2 layers |

**The horizontal split is the one that is easy to miss.** The height that has to pass under the gantry is not the finished envelope of the board - it is the GLUED STACK it is carved from, 203.2 mm, before a chip is cut. Against 149.9 mm of Z that is a 53 mm overshoot, not a near miss.

So **machine the halves and bond last**, rather than gluing the stack and then carving it:

| Piece | Layers | What gets cut |
|---|---|---|
| `*_Lower` | 1 + 2 | rocker and mast pocket on the underside; **lower** half of the cavity pocketed into the top face |
| `*_Upper` | 3 + 4 | deck crown on the top face; **upper** half of the cavity cut straight through |

Nothing goes under the gantry taller than 101.6 mm. Two things fall out for free: the deepest single pocket drops from ~124 mm (which would want a ~130 mm cutter that does not exist in 1/2 in for foam at sane money) to about 77 mm, and the 203 mm stack stops being an awkward thing to square up on a bed with 24.8 mm of side clearance.

Cost is one full-area glue line at mid-thickness, in EPS, where the skins carry the load - and the board already has three such lines between its four layers. This promotes one to the assembly joint. Alignment is the dowel-pin fixture already on the list for two-sided registration.

Bond order: **mid-plane first** (Lower to Upper, each side of the seam), which gives two full-thickness halves you can handle on a bench; then butt those at the vertical seam.

### How the four pieces are actually milled

**Five setups, one flip, no cradle.** Not eight - "4 pieces x 2 faces" is arithmetic, not a plan, because most of these faces have nothing on them. The cavity is entirely aft of the vertical seam, so both forward pieces are one-and-done.

| Piece | Setup | Face up | What gets cut |
|---|---|---|---|
| `Aft_Lower` | 1 | top | lower half of the cavity, 71.6 mm deep |
| `Aft_Lower` | 2 | bottom | rocker (3D) + mast block pocket — **the one flip** |
| `Aft_Upper` | 3 | top | deck crown (3D), cavity cut through, rim ledge, leash pocket |
| `Fwd_Lower` | 4 | bottom | rocker (3D). Top is the mid-plane — nothing on it |
| `Fwd_Upper` | 5 | top | deck crown (3D). Bottom is the mid-plane — nothing on it |

**Workholding: tape or vacuum to the spoilboard, every time.** Every setup presents a flat face — the as-glued slab face, or the mid-plane, or (for the flip) a top that has a pocket in it but is still flat all the way round it. **No cradle is needed anywhere**, and that is the real prize from splitting horizontally: machining a full-thickness board means holding a crowned deck while you cut the rocker into the other side, and that needs a cradle milled to match the deck. This plan never has to.

Only setup 2 is a flip, so the dowel-pin registration matters exactly once. Drill the dowel holes in the spoilboard and in the waste perimeter of the slab before any 3D work starts.

> **CUTTER REACH — CHECK THIS BEFORE THE DAY.** The deepest single pocket is the cavity's lower half at 71.6 mm. The O-flute the BOM buys (Freud 73-214) has a **cutting length of 31.8 mm** — that is its flute, not its overall length, and it is 39.8 mm short. Either buy a long-reach 1/2 in spiral with 75 mm+ of flute for that one pocket, or rough it with the ball nose and accept the stepover. Do not find this out with the foam already taped down.

### Station table

Width and thickness are the finished hull; rocker is the bottom's rise above the datum plane.

| Station (mm) | Width | Thickness | Rocker |
|---|---|---|---|
| 0 | 100.8 | 21.6 | 8.0 |
| 35 | 280.6 | 113.9 | 6.5 |
| 70 | 340.2 | 126.3 | 5.1 |
| 105 | 381.9 | 133.0 | 3.9 |
| 140 | 414.3 | 137.2 | 2.9 |
| 175 | 440.6 | 139.8 | 2.0 |
| 210 | 462.5 | 141.5 | 1.3 |
| 245 | 481.0 | 142.5 | 0.7 |
| 280 | 496.6 | 143.1 | 0.3 |
| 315 | 509.9 | 143.5 | 0.1 |
| 350 | 521.1 | 143.6 | 0.0 |
| 385 | 530.6 | 143.7 | 0.0 |
| 420 | 538.4 | 143.7 | 0.0 |
| 455 | 544.8 | 143.7 | 0.0 |
| 490 | 550.0 | 143.7 | 0.0 |
| 525 | 553.9 | 143.7 | 0.0 |
| 560 | 556.7 | 143.7 | 0.0 |
| 595 | 558.6 | 143.7 | 0.0 |
| 630 | 559.7 | 143.7 | 0.0 |
| 665 | 560.0 | 143.7 | 0.0 |
| 700 | 559.5 | 143.7 | 0.0 |
| 735 | 557.4 | 143.7 | 0.0 |
| 770 | 554.0 | 143.7 | 0.0 |
| 805 | 549.3 | 143.2 | 0.5 |
| 840 | 543.2 | 142.0 | 1.8 |
| 875 | 535.8 | 140.3 | 3.6 |
| 910 | 527.0 | 138.1 | 6.0 |
| 945 | 516.7 | 135.5 | 8.8 |
| 980 | 505.0 | 132.4 | 12.2 |
| 1015 | 491.7 | 128.8 | 16.2 |
| 1050 | 476.6 | 124.8 | 20.6 |
| 1085 | 459.7 | 120.2 | 25.7 |
| 1120 | 440.7 | 115.2 | 31.3 |
| 1155 | 419.4 | 109.5 | 37.6 |
| 1190 | 395.3 | 103.1 | 44.7 |
| 1225 | 367.9 | 96.0 | 52.6 |
| 1260 | 336.3 | 87.8 | 61.6 |
| 1295 | 299.2 | 78.5 | 72.0 |
| 1330 | 253.9 | 67.2 | 84.2 |
| 1365 | 193.4 | 52.8 | 99.8 |
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

## Two-day plan

**Day 1 — before layup**

1. EPS core — **4 pieces, 5 setups, 1 flip**. None taller than 101.6 mm; see the milling table above
2. Bond mid-plane (Lower+Upper), then butt at the vertical seam
3. Cavity caul (13)
4. Aluminium flat parts (4 module floor, 12 mast plate)
5. H80 lid cores (3, 11)

**Day 2 — after layup**

5. Trim the cured sandwich lids to net profile (2, 10)
6. Face the hatch lid underside flat in the same setup
7. Drill lid bolt clearance off the installed inserts

## Before booking

- Will they allow **EPS** dust? Still unanswered, and it is a woodworking shop with no published material policy. This is the one that can stop the booking.
- **Gantry clearance?** Now a nice-to-know rather than a blocker: the split sequence needs only ~112 mm. If they say 180+, the mid-plane bond can be skipped and the core goes back to two pieces.
- G10 is **no longer a question** — there is none in the build.
- Bed clears the longer half already: 1030 mm of 1210, and 560 mm of 610 across — but that leaves only 24.8 mm a side, so it has to be taped or vac-held, not clamped from the edges.

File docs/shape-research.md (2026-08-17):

# eFoil board shape — what production boards actually do

Research behind the V2 hull in `blender_board.py`. Everything here is either a
published manufacturer figure or measured off manufacturer orthographic renders
with `trace_reference.py`.

## Published dimensions

Lift quotes 4" (100 mm) thickness across its **entire** range — every board,
42 L to 83 L.

| Model | L (mm) | W (mm) | T (mm) | Vol (L) | bbox fill |
|---|---|---|---|---|---|
| LIFTX 4'3 | 1300 | 480 | 100 | 42 | 67.3% |
| LIFTX 4'7 (Florence) | 1400 | 520 | 100 | 49 | 67.3% |
| LIFTX 4'8 | 1420 | 530 | 100 | 52 | 69.1% |
| LIFTX 5'2 | 1570 | 580 | 100 | 64 | 70.3% |
| LIFTX 5'4 | 1630 | 620 | 100 | 70 | 69.3% |
| LIFT5 4'4 Pro | 1320 | 570 | 100 | 55 | 73.1% |
| LIFT5 4'9 Sport | 1450 | 640 | 100 | 67 | 72.2% |
| LIFT5 Laird 5'2 | 1570 | 600 | 100 | 64 | 67.9% |
| LIFT5 5'4 Cruiser | 1630 | 700 | 100 | 83 | 72.7% |
| Fliteboard Air Pro S3 | 1580 | 647 | 110 | 80 | 71.2% |
| Fliteboard Air Icon | 1740 | 698 | 115 | 110 | 78.7% |

**Production eFoils are ~100 mm thick and fill 67–73% of their bounding box.**

The V2 spec assumed 45–47% fill. That number is real, but it belongs to
surfboards and prone foil boards — thin tapered rails, pointed nose, domed
deck. An eFoil is a battery box you stand on: boxy rails, blunt ends, flat
deck, thickness held nearly constant over most of the length.

## Traced silhouettes

Two boards traced from Lift's ortho product renders. Scale checks out — the
traced width of the 4'3 came to 481.8 mm against a published 480 mm.

| | LIFTX 4'3 | LIFTX 5'4 |
|---|---|---|
| Planform area fraction | 0.818 | 0.827 |
| Wide point (station from tail) | 0.50 | 0.525 |
| Half width at 0.10 from tail | 0.62 | 0.70 |
| Half width at 0.10 from nose | 0.63 | 0.66 |
| Thickness plateau | 0.10 → 0.55 | 0.10 → 0.55 |

The two boards agree closely, so the shape law is scale-invariant.

### Planform — a superellipse, near symmetric fore/aft

`(1 - u^n)^(1/n)` about a wide point at 0.50, with `n = 2.1` on the tail half
and `n = 2.5` on the nose half. That reproduces the traced area fraction of
0.82 and both tip roundings, and it needs no separate nose/tail rounding fudge
— the vertical tangent at `u → 1` rounds the tips on its own.

Both ends are far blunter than a surfboard. Half width is still ~0.63 of max
at 10% from the nose.

### Thickness — a plateau, not a spindle

Full thickness from 0.35 to 0.55, only ~5% down at 0.10, then a taper to a
thin nose. **The deck is dead flat lengthwise through the middle third.**

This is the single most useful finding, because it is what lets a big hatch
sit on one flat sealing plane. A surfboard-style centred thickness peak makes
the deck fall away in both directions and the flat land pinches.

### Rocker

Dead flat aft of 0.55, then (scaled to length) 12 mm at 0.70, 29 mm at 0.80,
55 mm at 0.90. A square law through 95 mm hits all three. The V2 spec's 78 mm
starting at 0.55 was close — rocker was the one parameter already right.

### Section — boxy

Planform × thickness integrates to 0.72 of the bounding box. Lift lands at
67–73% overall, so the section itself must be ~0.87 of its own box. That is a
near-rectangular section: flat deck most of the way out, rail apex just past
mid-height, hard chine below it.

## The hatch

From the deck render of the 4'3:

- The hatch is **flush**. The traction pad runs straight across it; the joint
  is a hairline.
- It is large — roughly a third of the board's length, and most of the
  standing width.
- Two flush pull-latches on the rail-side edges. Not a bolt pattern.
- Charge port and status LEDs are on the lid itself.

## What changed in the model

| | V2 spec | Now | Why |
|---|---|---|---|
| Thickness | 150 mm | 125 mm | 150 mm is a SUP number. 125 is a compromise — still 25 mm over Lift, which a DIY pack and a bonded floor need. |
| Volume | 53.9 L target | 64.1 L result | Falls out of the shape; volume is an output, not an input. |
| bbox fill | 45–47% assumed | 64.3% | Matches the production band. |
| Deck crown | 3 mm | 2 mm | Trades directly against hatch width — see below. |
| Lid recess | 14 mm | 2.6 mm | Flush, pad bridges the joint. |
| Thickness dist. | peak at 0.46 | plateau 0.35–0.55 | Flat land for the hatch. |
| Planform | pull factors | superellipse 2.1 / 2.5 | Fitted to the traced boards. |

### Deck crown drives hatch width

The gasket land is a flat plane, so every mm of deck dome pulls the usable
opening inboard. Going from 5 mm of crown to 2 mm took the hatch from 198 mm
to 280 mm wide — a 41% gain for a change nobody can feel underfoot. This is
why production decks are all but flat over the pad.

Cavity position was swept across 5 lengths × 16 positions; 320–940 mm is
already the optimum, giving a 620 × 280 mm pack rectangle (V1's proven cavity
was 620 × 300).

## Open items

- 64.1 L gives −38.8 kg net float at 86 kg rider + 17 kg board. Still a sinker
  at rest, which is normal — Lift ships 42–70 L for the same job.
- 125 mm leaves 11 mm of compression column between the G10 plate and the
  cavity floor. It works, but it is the tightest part of the stack-up.
- Only Lift boards were traced. Fliteboard's hard boards would be a useful
  second opinion, but their spec page blocks scraping.

## Sources

- [LIFTX range](https://liftfoils.com/pages/liftx-efoil)
- [LIFT5 range](https://liftfoils.com/pages/lift5-efoil)
- [4'3 LIFTX product page](https://liftfoils.com/products/43-liftx) (ortho renders traced)
- [Fliteboard model overview](https://e-surfer.com/en/blog/fliteboards-the-fliteboard-model-overview-2025/)
- [foil.zone — What is the optimal board shape?](https://foil.zone/t/what-is-the-optimal-board-shape/713)

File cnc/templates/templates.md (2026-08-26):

# Templates

Cut from **12 mm MDF**. Every one comes off the parametric model, so nothing here needs measuring or tracing.

| Kind | Meaning |
|---|---|
| `BEARING` | cut at FINISHED size - flush-trim bit, bearing rides the template edge |
| `BUSHING` | cut OVERSIZE by the guide-bushing offset |
| `GAUGE` | not a router template - a shape gauge to check against |

Every template carries the centreline and station ticks on the `REG` layer. **`CHANNEL` lines are reference, not cuts.**

| Template | Size mm | Kind | What it does |
|---|---|---|---|

## The one number that is not from the model

`GUIDE_OFF = 5 mm` is the guide-bushing offset, and it depends on **your** bushing and cutter, not on the design. Every `BEARING` template above avoids it entirely by using a flush-trim bit instead - which is why they are all cut at finished size. Only the two seal-groove templates (parts 14 and 15, in `cnc/`) need it.

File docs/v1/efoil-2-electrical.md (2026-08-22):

> **V1 reference — not the current design.** This describes the board that was
> built, or early planning that predates the model. V2 is generated from
> `model/blender_board.py`; where the two disagree, the model and the docs
> linked from the [README](../../README.md) are correct.

# eFoil Build — Electrical & Battery (V7)

**Last updated:** August 7, 2026 (pack validated in service; kill switch status corrected)

---

## Battery Pack Design

**Configuration:** 14S9P, 126 cells (4 spares), 45Ah, ~2,331 Wh, 135A max continuous

**VALIDATED IN SERVICE (Aug 2026):**
- Cell spread **2 mV at rest, 6 mV under load** — the all-welded stacked-nickel architecture delivered exactly the uniform current distribution it was designed for
- **Zero overcurrent events** in the entire BMS log history
- Under a 78.8 A draw, pack voltage sagged only 56.8 V → 52.8 V. That is ~8.7 A per cell against a 15 A rating — the cells are barely working.
- Peak temp 31 °C charging, 26.9 °C discharging
- **Operating limits set to 100 A** at the VESC (~11 A/cell). BMS trip stays at 120 A as last-resort protection, deliberately above the operating ceiling so it never fires in normal riding.
- Cell type in the JK app is correctly set to **NCM/NCA** — this *is* lithium-ion; the BMS labels by cathode chemistry (NCM/NCA vs LFP vs LTO), not by the generic Li-ion umbrella.
- Charger: 58.8 V / 5 A, custom XT150 pigtail. Small connection spark on plug-in is normal inrush to the input capacitors, not a fault.

**Pack dimensions:** 211mm × 339mm × 82mm (9 cells wide × 14 rows deep in Heyiarbeit spacer brackets, single layer flat, cells standing upright. Cell spacing 22.3mm center-to-center within a row, 24.2mm row-to-row. Height includes nickel strips, 8AWG jumpers, Kapton, and shrink wrap on both faces. Confirmed via Onshape model.)

**Layout:** Zigzag serpentine pattern. Cells alternate orientation row-by-row — Row 1 has positive terminals facing up, Row 2 is rotated 180° (negatives up), Row 3 matches Row 1, etc. Series connections between adjacent rows are made via 9 individual bridging nickel strips per row boundary, with the 2 edge bridging strips reinforced for current capacity.

> **AS BUILT — the copper jumpers were not used.** The design below specifies 26 8AWG copper jumpers soldered along the edge bridging strips. The pack that was actually built reinforced those strips with **a second welded layer of nickel** instead, which is why the summary above calls it an all-welded stacked-nickel architecture. No solder went near a cell. Measured result was 2 mV spread at rest and 6 mV under load, so the substitution worked. **V2 follows the as-built version, not the design.** The copper-jumper section that follows is kept because its current-distribution analysis is still the reason the edges need reinforcing at all — only the method changed.

**Interconnect method — P-group strips + individual bridging strips:**

- **Nickel strip material:** SUIDI 0.2mm × 10mm × 5m pure nickel (99.6%), Amazon B0961Q1VVR. Two rolls ordered to cover the full pack (~7m needed total). 0.2mm is the sweet spot for the Battery Hookup capacitor spot welder (rated 0.3mm pure nickel max, performs best at 0.2mm), and 10mm width allows 2 weld spots per cell in a line down the center of each cell terminal.

- **28 P-group strips (parallel connections within each row):**
  - 14 strips on TOP face (one per row, running along all 9 cells of that row, ~210mm long)
  - 14 strips on BOTTOM face (one per row, ~210mm long)
  - Each P-group strip ties together the 9 cell terminals of its row into a parallel group
  - Every cell gets ONE weld on top face (to its row's top P-group strip) AND ONE weld on bottom face (to its row's bottom P-group strip)

- **117 individual bridging strips (series connections between rows):**
  - 13 row boundaries × 9 bridging strips per boundary = 117 strips
  - Each bridging strip is small (~30mm long × 10mm wide) and connects ONE cell in Row N to its partner cell in Row N+1
  - **Bridging strips alternate faces per boundary to prevent shorts:**
    - R1-R2 boundary: 9 bridging strips on TOP face
    - R2-R3 boundary: 9 bridging strips on BOTTOM face
    - R3-R4 boundary: 9 bridging strips on TOP face
    - ...alternating, 7 boundaries on top + 6 boundaries on bottom = 13 total
  - Why alternate: if both faces had bridging strips at the same boundary, you'd short the pack through the cells
  - Each cell gets a SECOND weld on one face (to a bridging strip) in addition to its P-group strip weld on that same face

- **26 × 8AWG copper jumpers (current capacity reinforcement):**
  - 2 jumpers per row boundary (on the leftmost and rightmost bridging strips of that boundary)
  - Each jumper is a short piece of 8AWG silicone wire (~25-30mm), soldered along the length of the bridging strip to add copper in parallel with the nickel
  - 13 boundaries × 2 edge jumpers = 26 jumpers total
  - Middle bridging strips (the 7 inner ones at each boundary) are pure nickel only — no jumpers needed because 9 parallel nickel paths already distribute current well

- **Weld count per cell:** Each cell has 2 terminals (top and bottom). Each terminal gets:
  - 1 weld to its P-group strip (parallel connection)
  - 1 weld to a bridging strip (series connection to next row) — but only on ONE face per boundary
  - Total: 4 welds per cell (2 on top, 2 on bottom) × 2 spot welds per point = ~8 spot welds per cell × 126 cells = ~1,000 welds total
  - Actually refined count: 252 cell terminal positions × 2 welds per P-group connection + 252 cell terminal positions × 2 welds per bridging strip connection = ~1,008 welds

- **Pre-weld workflow:** Pre-solder the 26 edge bridging strips with their 8AWG jumpers on the bench BEFORE welding to cells. No soldering heat near cells, ever. Middle bridging strips go in plain (no jumpers).

**End collectors (pack terminals):**

- **Pack +** on top face of Row 1: the Row 1 top P-group strip itself IS the Pack + terminal — a full-length 8AWG bus wire soldered along its length provides the low-resistance current path out of the pack. Terminates in XT150 positive pigtail exiting the battery enclosure.
- **Pack −** on bottom face of Row 14: the Row 14 bottom P-group strip IS the Pack − terminal — full-length 8AWG bus wire soldered along its length. Routes to BMS B− terminals (see wiring chain below).

**Balance leads:** JK BMS ships with pre-made 15-wire balance harness. Wires solder directly to the P-group strip of each row at the series junction points. Wires 1 and 15 double as pack voltage sensing (no separate B+ power terminal needed — see "Common-port BMS" section below).

**Main leads:** 8AWG silicone wire, XT150 connectors on short pigtails exiting the battery enclosure through cable glands.

**Pack wrapping sequence:**
1. Kapton tape over all exposed nickel + solder joints on both faces of pack
2. Heat shrink wrap around entire cell pack (top, bottom, sides) — single PVC shrink tubing sleeve
3. BMS sits on top of shrink-wrapped pack (NOT inside shrink wrap — BMS must remain separable for diagnostics/replacement)
4. Small dabs of silicone sealant between BMS corners and pack top to hold BMS in position against vibration

**Current demands:** Cruising ~15-25A battery, water-start extended 60-120s at 50-70A, takeoff peaks ~70-100A (1-5s bursts). Per cell at takeoff: ~8-11A (well under 15A rating).

**Why this architecture handles current well:**
- **Series current distributes across 9 parallel bridging strips per junction.** At 100A pack peak, each bridging strip carries ~11A — well within the 25A continuous rating of 0.2×10mm pure nickel.
- **The 2 edge bridging strips have 8AWG copper jumpers soldered along them.** At those 2 locations, copper (16.6 mm² via single 8AWG) is in parallel with nickel (2.0 mm²). Copper is ~4× more conductive per mm², so conductance ratio is ~8:1 copper vs nickel per edge strip. Copper carries ~89% of the current at edge bridges.
- **Effective current split across 9 bridging strips at a junction:**
  - 2 edge strips each carry ~25A total (23A copper + 2A nickel)
  - 7 middle strips each carry ~11A (all nickel)
  - Total: 2×25A + 7×11A = 127A capacity vs 100A peak demand — 27% margin
- **P-group nickel strips only carry parallel balancing current** (milliamps to low amps between cells), not pack-level current. Width is not a bottleneck.
- **Redundancy:** If any single bridging strip or jumper fails, 8 others continue carrying current. No single point of failure.
- This approach is community-standard on foil.zone for high-current builds.
- Alternative approaches considered and rejected: true copper-nickel sandwich (welder power inadequate), nickel-plated copper (requires separate nickel layer on top to weld reliably), wider/thicker pure nickel strip (not needed given 9-parallel-strip redundancy).

## BMS Placement on Pack

**Position:** BMS sits flat on top of the shrink-wrapped pack, centered on the pack's long axis. Oriented with its long edge parallel to the pack's long axis.

**Clearance for jumpers:** The 26 8AWG jumpers sit along the two long edges of the pack (one pair per row boundary, one on each edge, but alternating which face — so 13 jumpers on top face edges, 13 on bottom face edges). The BMS footprint (162 × 102mm) is narrower than the pack (211 × 339mm), so ~54mm of pack top is exposed on each long edge for jumper routing. BMS does NOT sit on top of jumpers — BMS sits on flat P-group strip area only.

**Common-port BMS configuration:** The JK BD6A20S15P is a common-port (common positive) BMS — it switches only the negative rail. Pack + is a straight pass-through that never goes through the BMS.

**BMS terminal layout (per listing):**
- **2× P−** on one short edge (ESC/load side, downstream of MOSFETs) — parallel wires for high-current capacity
- **2× B−** on opposite short edge (pack side, upstream of MOSFETs) — parallel wires
- **No dedicated B+ terminal** — pack positive is monitored via balance wire #15 (connects to Row 1 top, pack absolute positive)
- **Balance harness** exits the bottom edge of the BMS, fans out to the 15 series junction points

**Current flow (discharge):** Pack + bus bar → XT150 positive (direct, bypasses BMS) → ESC. Pack − bus bar → 2× 8AWG wires → BMS B− terminals (parallel) → through MOSFETs → BMS P− terminals → 150A ANL fuse → XT150 negative → ESC.

**Current flow (charge):** Charger + → XT150 positive → Pack + (direct). Charger − → XT150 negative → fuse → BMS P− → MOSFETs → BMS B− → Pack −. BMS can cut off charge if any cell hits overvoltage.

**Wiring chain:**
```
Pack + bus bar → 8AWG → XT150+ pigtail (direct, never touches BMS)
Pack − bus bar → 2× 8AWG → BMS B− (×2) → BMS MOSFETs → BMS P− (×2) → 2× 8AWG → 150A ANL fuse → 8AWG → XT150− pigtail
XT150 pair (out of battery enclosure) → CESFONJER IP68 housing → XT150 into ESC enclosure → 75200 Pro V2 ESC
3× Phase wires out of ESC → 3× CESFONJER IP68 housings → XT150 phase connectors → plywood wire hole → Gong top plate → hollow mast → motor
```

## Height Stackup (fits in 106mm internal enclosure cavity)

| Component | Height | Running total |
|---|---|---|
| Bottom of cells sitting on silicone-sealed aluminum plate | 0mm | 0mm |
| Cells (bottom nickel strips already welded) | 70.2mm | 70.2mm |
| Top nickel strip on center of pack (under BMS) | 0.2mm | 70.4mm |
| Kapton + heat shrink over pack | 0.5mm | 70.9mm |
| BMS sitting flat on shrink-wrapped pack center | 22mm | 92.9mm |
| Top clearance to aluminum top plate | 13.1mm | **106mm** |

**Jumpers (4.5mm stackup of 8AWG + solder) live in the side margins** alongside the BMS, not under it. They occupy lateral space (~43mm wide per side), not vertical space.

## Anti-Spark Operation

The BMS provides soft-start anti-spark when it turns ON (MOSFETs close gradually over ~1 second). This works ONLY if the XT150 is already mated when the BMS powers on — i.e., BMS must be OFF during connector mating.

**Natural safe workflow (no sparks):**
1. Post-ride: press BMS button OFF → unplug ESC XT150 (no spark, P− open) → plug in charger XT150 (BMS still off) → charge overnight
2. Pre-ride: unplug charger XT150 (BMS still off) → plug in ESC XT150 (no spark, P− still open) → close hatch → press BMS button ON → soft-start ramps up → ride

**Connector mating always happens while BMS is off** — this is the natural sequence, not a special precaution. Sparks only possible if workflow is deviated from.

**If uncertain of BMS state** (e.g., after someone else rode): check JK BMS Bluetooth app before opening hatch. App connects → BMS is on → send power-off command via app before unplugging anything. App doesn't connect → BMS is off → safe to proceed.

---

## Charging

58.8V 5A charger (XLR plug removed, rewired to XT150 male). Unplug ESC from battery XT150, plug charger XT150 into same battery connector. Or remove battery box entirely and charge at home. BMS handles active balancing automatically via Bluetooth app monitoring. ~9 hour charge time.

---
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

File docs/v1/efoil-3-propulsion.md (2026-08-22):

> **V1 reference — not the current design.** This describes the board that was
> built, or early planning that predates the model. V2 is generated from
> `model/blender_board.py`; where the two disagree, the model and the docs
> linked from the [README](../../README.md) are correct.

# eFoil Build — Propulsion (V3)

**Last updated:** August 7, 2026 (as-built — mount assembled, prop mounted, real performance data)

---

## Motor
- Flipsky 65161 120KV (round, threaded shaft)
- Threaded 12mm shaft for community prop STL compatibility

## ESC
- Flipsky 75200 Pro V2.0 (aluminum PCB, 130×68×41mm)
- Built-in power button (not used — BMS switch handles power on/off)

## Remote
- Flipsky VX3 Pro remote + wireless receiver module

## Foil
- Gong Allvator V2 complete setup (Bons Plans):
  - Alu Mast V2 85cm (hollow — rubber plugs for wire access)
  - Top Plate Alu V2
  - Mast Fuselage Connector V2
  - Pro Alu Fuselage V2 (Regular)
  - Front Wing X-Over V2 XL (1,650 cm²)
  - Stab X-Over V2 48cm (335 cm²)
  - Complete Screw Kit Alu Foil V2

---

## Propeller
- Flipsky 65161 Propeller — 160mm diameter, 1.1 pitch, 3-blade
- Designed for the 12mm threaded shaft with M8 nut — plug-and-play, no adapter needed
- STL source: MakerWorld https://makerworld.com/en/models/433274
- Community reports: very good tolerances, snug shaft fit, blades thicker than aluminum equivalents (good for printed rigidity)
- Print: Lime green PETG, 0.4mm nozzle, 0.12mm layer height, 100% infill
- Post-processing: Sand 120→220 → brush coat TotalBoat epoxy → cure → wet sand 400→600-800 → second epoxy coat → wet sand → balance check (hang on bolt through center bore, sand heavy blade)
- Print 4-5 copies as spares

**Prop decision notes:** Community (DutchFoiler, Foilguy on foil.zone) recommended Flite prop ($45) with bore modification (ream to 12mm + pin adapter, ~$70 all-in). Decided to start with the MakerWorld 3D printed prop since it's plug-and-play for our shaft and free to print. Flite prop remains a backup option if printed props don't perform well. Flipsky's stock aluminum prop is universally considered poor for eFoils — skip it. DutchFoiler shared Flite prop drill guide STL: https://www.printables.com/model/583026-flite-prop-drill-guide

---

## Motor Mount
- jkoljo's FS65161 motor mount for Gong V2 mast (community-designed, proven, multiple builders confirmed fit)
- Thingiverse: https://www.thingiverse.com/thing:5996522
- **Configuration: No tail support, no shroud** — reduces drag, simplifies assembly
- Mount can be assembled without removing motor wires from mast
- Files to download (STEP format — Bambu Studio imports STEP natively):
  1. Gong_V2_mast_front_clamp.STEP
  2. Gong_V2_mast_rear_clamp_rev2.STEP (use rev2 — updated June 2023, fixes bolt pattern)
  3. Gong_V2_mast_clamp_nose_cone.STEP
  4. Gong_V2_mast_clamp_cable_cover.STEP
- Print: Lime green PETG, 0.6mm nozzle, 0.25mm layer height, 5 perimeters, 3 top/bottom layers, 40% triangular infill. Consider higher infill on front clamp (taking load without tail support).
- Optional: sand and epoxy coat mount parts to match board finish (purely cosmetic — they're underwater)
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

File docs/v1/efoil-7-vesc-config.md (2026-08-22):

> **V1 reference — not the current design.** This describes the board that was
> built, or early planning that predates the model. V2 is generated from
> `model/blender_board.py`; where the two disagree, the model and the docs
> linked from the [README](../../README.md) are correct.

# eFoil V1 — VESC Configuration Reference (v2)

**Originally configured:** June 12, 2026 (bench commissioning)
**Last updated:** August 7, 2026 (power diagnosis session — limits raised, throttle retuned)
**Hardware:** Flipsky 75200 Pro V2 (reports as HW 75_300_R2) + 65161 120KV + VX3 Pro remote
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

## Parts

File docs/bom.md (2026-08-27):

# eFoil V2 - full bill of materials

For **2 boards**, 1 pack of cells already on hand. Regenerate with `python model/bom.py 2`.

Sheet counts come from the live cut list and fastener counts from the model, so they cannot drift from the design. `verified` means read off the supplier's page or your own receipt; `estimate` means my number.

## 1  Core and shaping

| Item | Qty | Unit | Unit $ | Ext $ | | Note |
|---|---:|---|---:|---:|---|---|
| [EPS rigid foam 2in x 48in x 8ft (HD 202532856)](https://www.homedepot.com/p/Henry-2-in-x-48-in-x-8-ft-R-7-7-EPS-Rigid-Foam-Board-Insulation-320825/202532856) | 4 | sheet | $27.68 | $110.72 | verified | HD Meridian, 30 in stock, aisle 29 bay 020; $23.53 at 32+. EPS, not the XPS V1 used - deliberate, ~$90 cheaper across both boards, and the shear it gives up is covered by H-80 at the hardpoints. See the note at RHO_EPS in blender_board.py |
| [PL300 / Gorilla Glue, layer glue-up](https://www.amazon.com/dp/B0009XEGVC) | 2 | tube | $6.59 | $13.18 | estimate |  |
| [Maker Shop Boise Basic month](https://www.makershopboise.com/membership) | 1 | month | $150.00 | $150.00 | verified | month-to-month, and the plan is to cancel at the end of it. TWO VISITS, and the second one is the scheduling risk. First: EPS core, both Divinycell lid cores, three MDF guides. Second: both laminated lids, profile and holes in one setup each. The month allows 8 visits so two is easy - what is NOT easy is that the second one needs the LIDS LAID UP, which means the vacuum rig has to be working three weeks earlier than the build order otherwise wants it. If that slips, a $99 day pass buys the second visit later, or the MDF masters do the lids at home. A $250 punch pass still is not worth it |
| **subtotal** | | | | **$273.90** | | |

## 2b Aluminium

| Item | Qty | Unit | Unit $ | Ext $ | | Note |
|---|---:|---|---:|---:|---|---|
| [5052 1/8in x 12 x 24, 2-pack - module floors](https://www.amazon.com/dp/B0D3TH4TTC) | 1 | pk | $61.99 | $61.99 | verified | your Apr 2026 receipt (MorningRo/Huaiian). One sheet is one floor, so this pack does both boards |
| [6061-T651 1/2in x 12 x 18 - mast plates](https://www.speedymetals.com/pc-2411-8360-12-6061-t651-aluminum-plate.aspx) | 1 | sheet | $88.92 | $88.92 | verified | speedymetals.com 61p.5; both plates nest, 2 x 6.89in of 18, 4.2 spare. Saw-cut edge, +/-1/4in - profile it yourself |
| **subtotal** | | | | **$150.91** | | |

## 3  Structural foam

| Item | Qty | Unit | Unit $ | Ext $ | | Note |
|---|---:|---|---:|---:|---|---|
| [Divinycell H-100 1/4in quarter 21x42, hatch lid cores - 2 sheets bonded to 1/2in](https://fiberglasssupply.com/1-4-in-h-100-divinycell-quarter-sheet-21-x-42/) | 2 | sheet | $49.59 | $99.18 | verified | fiberglasssupply.com; no 1/2in H-100 is made |
| [Divinycell H-80 1/4in quarter 24x48, module lid cores](https://fiberglasssupply.com/quarter-sheet-1-4-h-80-divinycell-plain-sheet/) | 1 | sheet | $53.94 | $53.94 | verified | L18-1070; nobody stands on this one |
| [Divinycell H-80 3/4in quarter sheet 24x48, mast block + leash pad](https://fiberglasssupply.com/quarter-sheet-3-4-h-80-divinycell-plain-sheet/) | 1 | sheet | $100.26 | $100.26 | verified | L18-1112, 24x48. Was 2 sheets when it carried 2 shear ribs |
| **subtotal** | | | | **$253.38** | | |

## 4  Laminate

| Item | Qty | Unit | Unit $ | Ext $ | | Note |
|---|---:|---|---:|---:|---|---|
| [E-glass 6 oz, 50in x 12ft, 2-pack](https://www.amazon.com/dp/B0CQY5KX84) | 2 | pack | $19.99 | $39.98 | verified | your receipt |
| [1708 biax, 50in x 10 yd roll](https://www.amazon.com/dp/B07RJWHPKG) | 1 | roll | $79.95 | $79.95 | verified | 6 yd needed across both boards; $8.00/yd against Fibre Glast's $12.50 and no freight |
| [TotalBoat 5:1 FAST hardener 6 oz, cold days](https://www.amazon.com/dp/B00HRHA59K) | 1 | ea | $27.99 | $27.99 | verified | min 40-45 F against slow's 60. In a cold shop this is the one that cures, and the cold gives the pot life back. 6 oz catalyses ONE QUART of resin, which is about a single hull session - if the shop turns out to be cold for the whole build, the 25 oz at $61.99 does a full gallon and is the cheaper way to get there |
| [TotalBoat 5:1 gallon kit, slow hardener](https://www.amazon.com/dp/B00HR8515C) | 2 | kit | $149.99 | $299.98 | verified | 2.51 m2 laminate = 4.8 kg mixed = 1 kit/board |
| [TotalBoat 5:1 quart kit, fillets and bonding](https://www.amazon.com/dp/B00HR8517A) | 1 | kit | $58.99 | $58.99 | verified |  |
| Fumed silica thickener | 0 | off | $0.00 | $0.00 | on hand | plenty on hand from V1 |
| **subtotal** | | | | **$506.89** | | |

## 5  Vacuum bagging

| Item | Qty | Unit | Unit $ | Ext $ | | Note |
|---|---:|---|---:|---:|---|---|
| [VECOTOOLS 4.5 CFM single-stage pump, oil incl.](https://www.amazon.com/dp/B0GZVLP3PL) | 1 | ea | $57.99 | $57.99 | verified | your listing, ASIN B0GZVLP3PL. Was a $139.99 Pittsburgh 2-stage plus $15 of oil - $97 for ultimate vacuum we must not use |
| [VR20 vacuum regulator](https://www.easycomposites.us/vacuum-regulator-for-vacuum-bagging) | 1 | ea | $52.00 | $52.00 | verified | one-time. Holds the bag at 5-10 inHg, which is the whole ball game: EPS crushes around 150 kPa and full vacuum is 101. Hose tails are +$4.70 if you want them |
| [Bag connector w/ ball valve, 1/4 in QD](https://www.amazon.com/dp/B0FSKGGL8H) | 2 | ea | $19.59 | $39.18 | verified | THE BALL VALVE IS THE POINT: shut it and the bag is isolated from the pump, so leak-down is a real measurement and not a guess about whether the pump is keeping up. Two of them - a 1400 mm hull bag pulls down far faster from both ends, and one is a spare |
| [Vacuum hose + hose clamps](https://www.amazon.com/dp/B0FH52FT4G) | 1 | set | $11.61 | $11.61 | estimate | 1/2 in tubing pump-to-bag plus clamps; the other half of what the deleted kit was actually carrying |
| [Test cap + tubing, module leak test](https://www.amazon.com/dp/B0DPWRP6FR) | 1 | set | $22.99 | $22.99 | estimate | PROVE THE MODULE BEFORE THE CELLS GO IN, and prove it the way the failure actually happens: run one of the kit's smaller hoses through an empty PG11 gland and tighten it - that is your test port - blank the other glands and the vent boss, seal it empty, pull 5 inHg, shut the ball valve and watch the gauge for 30 min - porosity reads as a slow bleed. Then do it again SUBMERGED: under vacuum any path pulls water IN and you see exactly where. V1 found its leaks by riding |
| [Vacuum gauge, -30 inHg, 1/4 NPT, glycerin](https://www.amazon.com/dp/B00VQSOZFQ) | 1 | ea | $10.50 | $10.50 | verified | reads the BAG, not the pump - tee it in at the bag end. The regulator sets the level; this is how you know it worked. GLYCERIN FILLED on purpose: a dry needle flutters with every pump stroke and you cannot read 7 inHg off it, which is the one number that matters |
| [Vac bag film, 5 yd](https://www.amazon.com/dp/B079MBL5TX) | 3 | roll | $24.95 | $74.85 | verified | 3.06 m2 a hull session; 2 hulls + 4 lids + a practice piece + one re-do. Single-use on the hull, reusable on flat parts. Same Elite Lab product Fibre Glast sells, at the same price, with free delivery |
| [Peel ply, 60in](https://www.amazon.com/dp/B0H5JTMTZ3) | 6 | yd | $18.99 | $113.94 | verified | was only in the starter kit, and one kit's worth does not cover 6.12 m2 of part |
| [Breather / bleeder cloth](https://www.amazon.com/dp/B015NM0B8K) | 6 | yd | $13.95 | $83.70 | verified | $13.95/yd cut; a 5 yd roll at $59.99 is $12.00/yd if you would rather buy the roll |
| [Sealant tape, 50 ft roll](https://www.amazon.com/dp/B0GF25BPN6) | 2 | roll | $19.99 | $39.98 | verified | 31 m of bag perimeter across the project. 2 x 50 ft at $19.99 replaced 4 x 25 ft at $12 - same tape, fewer joins |
| **subtotal** | | | | **$506.74** | | |

## 6  Hatch and seal

| Item | Qty | Unit | Unit $ | Ext $ | | Note |
|---|---:|---|---:|---:|---|---|
| Neat epoxy, sealing every cut laminate edge | 0 | off | $0.00 | $0.00 | on hand | off the laminating kit. Groove walls, lid perimeter, all 12 lid bores, every machined edge. This is V1's Test 2 verbatim - water came in through unsealed fibre ends at the cavity ledge, and its own note reads: cured laminate is NOT waterproof at a cut edge |
| [Solid silicone cord, 1/8 in (3.175 mm) - the spare size](https://www.amazon.com/dp/B00QVB0KE8) | 1 | pc | $15.39 | $15.39 | verified | 10 ft piece, 70A. Fitted ONLY if the routed groove measures deep. Gives 24% squeeze at the nominal 2.4 depth and 15% at a bad 2.7 - the true 3.5 mm that would give 23% at 2.7 is an industrial-supply size, so if the groove really comes out at 2.7 the answer is to fix the groove, not to chase cord |
| [Solid silicone cord, 3 mm round - BOTH seals](https://www.amazon.com/dp/B096N67R2D) | 2 | pc | $17.59 | $35.18 | verified | 10 ft (3.05 m) pieces, 70A. Buy long - splice on a straight run, never a corner |
| [Paste wax, releasing the groove filler](https://www.amazon.com/dp/B0GVCGHZFR) | 1 | ea | $16.99 | $16.99 | estimate | the filler must NOT bond - it comes back out after the glass goes over it |
| [2.5 mm straight cutter, opening the seal groove](https://www.amazon.com/dp/B0GWSZ2KV2) | 1 | ea | $7.99 | $7.99 | estimate | NOT a fallback any more. The groove filler prints FLUSH and this opens the groove, off template 14 located on the rebate wall. The scheme it replaces printed the filler 0.5 mm proud and sanded down to it - self-finding, but it ran a 0.5 mm step 1.8 m along the SEALING land, and glass bridges at the corners of a step. Undersize in a 4 mm groove on purpose: 0.75 mm of lateral slop each side before the cutter can touch the land |
| [Black epoxy pigment, marking the lid plugs](https://www.amazon.com/dp/B09NYDCXBQ) | 1 | ea | $8.99 | $8.99 | estimate | a few drops in the plug epoxy for both lids - 30 plugs a board and a 50 ml bottle is a lifetime. Not decoration: it is what the drill guides register on |
| [Black wax filler sticks, blocking + marking the bolt holes](https://www.amazon.com/dp/B0CCDL8XNV) | 1 | pk | $7.99 | $7.99 | estimate | 24 holes across both boards - one stick does the lot. Not a structural part; it is a plug and a marker |
| [Silicone adhesive, bonding the cord into groove](https://www.amazon.com/dp/B0002UEN1U) | 1 | tube | $7.56 | $7.56 | estimate | a thin continuous bead under the cord. It cannot then migrate, lift out, or be pinched under the lid in a dark car park. THIS IS ALSO THE SPLICE ADHESIVE - butt the two cord ends in it rather than reaching for cyanoacrylate, which does not bond silicone. Done that way the splice is a few mm of pour-in-place silicone cast in the groove, not a glued butt joint |
| [M5 x 25 button head TORX TX25, 25 pk](https://www.amazon.com/dp/B08BZJPJTK) | 1 | pk | $15.99 | $15.99 | estimate | 24 needed of 25. TX25 drive. ISO 7380-2 flanged button; the model draws the plain O9.5 x 2.75 high, which is what the model draws and what puts the whole stack 1.5 mm BELOW the deck pad. 304 not A4 - see the note above, it is a deliberate trade and the captive nut stays A4. Tef-Gel every one. A4 SOCKET CAP B0CJFMMF58 is the fallback if the grade matters more than the toe |
| [M6 penny washer O18 A4 DIN9021](https://www.amazon.com/dp/B0DB8RBY3N) | 1 | pk | $12.99 | $12.99 | estimate | 58 needed - TWO PER BOLT, one captive under the nut and one UNDER THE HEAD. M6 size on an M5 bolt: the 0.7 mm of slop is irrelevant on a washer and the 3 extra mm of OD is not |
| [M5 A4 hex nut DIN934, 50 pk - CAPTIVE in the ring](https://www.amazon.com/dp/B084HLMN7B) | 1 | pk | $9.19 | $9.19 | verified | 34 needed. Dropped in at a print pause at Z=6.0; steel thread, so a hatch that comes off every ride never wears anything out |
| [MDF 12 mm 4x8 sheet, three lid/ring guides](https://www.homedepot.com/p/ULTRASTOCK-1-2-in-x-4-ft-x-8-ft-MDF-Panel-M31240849097000000A/202332602) | 1 | sheet | $50.00 | $50.00 | estimate | THREE parts, and the sheet is sized by LAYOUT not area: 14_groove_guide 580 x 391, 17_hatch_lid_master 577 x 388, 16_module_lid_guide 443 x 314. That is 0.59 m2 - 80% of a 2x4 panel by area, and it will not nest on one: the two big ones take a 391 mm band across the width and leave a 219 mm strip the third cannot use. templates.py shelf-packs them now rather than checking each part alone |
| **subtotal** | | | | **$188.26** | | |

## 7  Module

| Item | Qty | Unit | Unit $ | Ext $ | | Note |
|---|---:|---|---:|---:|---|---|
| Epoxy wash coat, BOTH faces of the printed shell | 0 | off | $0.00 | $0.00 | on hand | off the laminating kit. Outside face first - that is the wet one. Keep it OFF the gasket flange and the insert faces; a soft film at a clamping surface undoes the seal geometry, which is V1's own warning about Flex Seal |
| [M4 x 12 A4 socket cap DIN912, 10 pk](https://www.amazon.com/dp/B07DVPC7HT) | 4 | pk | $7.10 | $28.40 | verified | 36 needed. A4/316 again - the $0.09/ea listings are all A2/304 |
| [M4 A4 washer, 316, 100 pk](https://www.amazon.com/dp/B0DZ5BVLP5) | 1 | pk | $6.79 | $6.79 | verified | 36 needed, under every lid bolt. NOTE the OD is 12 mm, not the 9 mm this line specced - the only 9 mm-OD listing is 304. Took the alloy over the diameter because this sits where the cavity floods. CHECKED, and it did NOT clear: at the old bolt circle a 12 mm washer reached to 0.5 mm of the lid edge, and so did the epoxy plug backing it. The bolt circle moved inboard 1.5 mm instead of the alloy moving down - see MOD_BOLT_EDGE. Both clear by 2.0 now, and every other flange number got better rather than worse |
| [M4 x 12.7 LONG brass heat-set insert, 50 pc](https://www.amazon.com/dp/B07473ZV71) | 1 | pack | $14.00 | $14.00 | estimate | 36 needed; 5.6 mm printed pilot |
| [ASA filament, printed rim ring](https://www.amazon.com/dp/B09DKPYYBP) | 2 | kg | $24.49 | $48.98 | verified | 6 dovetailed pieces/board at ~90% infill, 710 g of part each; PRINT SEAL FACE DOWN - the bed is flatter than any top surface |
| [Acetone, solvent-welding the printed joints](https://www.homedepot.com/p/Klean-Strip-1-qt-Acetone-Thins-Fiberglass-Resins-Epoxy-and-Adhesives-QAC18/100144922) | 1 | qt | $11.48 | $11.48 | estimate | ASA dissolves in it like ABS - a brushed acetone/scrap slurry makes the joint one piece of plastic, not an adhesive line |
| [ASA filament, printed module shell](https://www.amazon.com/dp/B09DKPYYBP) | 3 | kg | $24.49 | $73.47 | verified | 4 L-pieces/board, ~1.13 kg of part + supports and brim; largest piece 226 x 146 fits the A1 bed |
| [Sikaflex-292 marine structural PU](https://www.amazon.com/dp/B008F8VYMM) | 1 | tube | $28.99 | $28.99 | verified | ~6-8 MPa vs 4200's ~2. Fillet BOTH sides of the joint - on a flexible bond the fillets are what stop it peeling |
| [Sika Aktivator-PRO 250 ml + daubers](https://www.amazon.com/dp/B0D9KTLC1M) | 1 | ea | $28.95 | $28.95 | verified | abrade + solvent wipe + activate the 5052; scuff the ASA. Aktivator-205 is DISCONTINUED - Aktivator-PRO replaces it. UPGRADE PATH: full Primer-206 G+P is the belt-and-braces answer for immersed PU on metal but is $67/250 ml on Amazon. Skipping it is defensible HERE only because the bond line is mechanically backed by the flange bolts and the gasket - not the PU - is the water barrier |
| [2 mm glass beads or shim wire, bond-line control](https://www.amazon.com/dp/B0FVSHYP99) | 1 | ea | $7.19 | $7.19 | estimate | clamping a PU joint metal-to-plastic squeezes the line out and puts you back to a rigid joint that will fail |
| Hollow punch set 1/8-1/2in + cutting mat | 0 | off | $0.00 | $0.00 | on hand | 7/32 in (5.556) is the size for M4 - the model sizes the gasket holes off it, not the other way round. Punch onto a mat: a hard bench rolls the edge on the first hit |
| [Closed-cell sponge EPDM 1/8in, module lid gasket](https://www.amazon.com/dp/B07FWQM34V) | 1 | roll | $13.99 | $13.99 | verified | blank is 443 x 314 mm a board; the roll is 432 wide so it nests across, and 2032 long does both with room over |
| [Gebildet PG11 gland, M18x1.5, 30 pk](https://www.amazon.com/dp/B0B8NJR62L) | 1 | pk | $9.99 | $9.99 | verified | your listing: M18x1.5 thread (matches the 18.5 hole) and 5-10 mm cable, against our 6.5 mm 8 AWG. 6 needed of 30 - one wire per gland; three in one gland deforms the insert into a clover and leaks between them |
| [Neoprene sheet 1/2in, wire bung](https://www.amazon.com/dp/B01LX83X9H) | 1 | sheet | $16.00 | $16.00 | estimate | 1/2 in. The blocker takes 4 mm off the top of the plate's bore, so the bung has 8.7 of it - and a 12.7 disc in a 8.7 space hangs 4.0 proud, which is the squeeze, and the mast's own plate is what applies it. Punch O30.0 discs and drill 3 x O5.5 IN A ROW at 7.5 pitch. The row is the order the leads leave the mast in, so none has to be twisted. One sheet is a lifetime of bungs for both boards |
| [Hollow punch set 3/16-1-3/8in, for the O30 bung](https://www.amazon.com/dp/B07PQYRG9K) | 1 | set | $32.99 | $32.99 | estimate | the existing set stops at 1/2 in and the disc is O30.0 - the 1-3/16 in punch is 30.16, near enough in rubber. This line used to say 'for the O31.75 bung', which was the disc diameter two designs ago and would have had you reaching for the 1-1/4 punch |
| Printed ASA wire blocker | 0 | off | $0.00 | $0.00 | on hand | printed, grams off the rim ring spool. O30.4 x 4 body inside the PLATE's bore, O24.6 x 12 spigot up into the FOAM's, 23 x 7 SLIT for the leads. The slit is CLEARANCE and seals nothing; the bung does that, one hole per lead. BED THE SPIGOT PROPERLY ON 4200 - that bond is the load path, not the foam ring it lands on: the ring is 254 mm2 at 2.5 MPa against H80's 1.4 and would crush in on its own, while the bond is 927 mm2 in shear at 2.9x. Goes in at STEP 7, from below, before the plate |
| [3M 4200 FC 3 oz tube, skim over the bung](https://www.amazon.com/dp/B00MJ9K78A) | 1 | tube | $17.99 | $17.99 | verified | does both boards; 4200 NOT 5200 - 5200 never comes out. NOT A BARRIER in the channel any more - the blocker is bedded on it and the bung's own holes seal the leads. This line is that bedding plus a skim over the bung's face |
| [GORE PolyVent Stainless M12x1.5, module vent](https://www.branom.com/shop/6560-200-1-gore-screw-in-vent-port-black-pmf100320-m12-x-1-5-543016) | 2 | ea | $15.00 | $30.00 | estimate | PMF200444. NOT optional on a sealed lithium box - and see the note at the vent in blender_board.py for what it does NOT do: at 1.6 L/min it is a BREATHER, not runaway relief, which wants about 12 L/min for one cell. Torque 0.9 +/- 0.3 Nm, 18 mm wrench, silicone O-ring, 316L body. THREAD IS M12 x 1.5 - the part this replaced was M12 x 0.75, so the printed boss changes with it |
| GORE counter nut M10510-008, brass | 2 | ea | $3.00 | $6.00 | estimate | nickel-plated brass, for the stainless PolyVent. The wall is 4 mm of printed ASA; a nut spreads the load the way the PG11 glands already do rather than trusting a thread in the print |
| [M12 IP68 momentary panel button](https://www.amazon.com/dp/B0FPQP7CP9) | 1 | ea | $32.65 | $32.65 | verified | 1 on hand; this line buys the second board's |
| [JST GH 1.25 mm pigtail pair, BMS switch](https://www.amazon.com/dp/B07FP2FCYC) | 1 | pk | $5.99 | $5.99 | verified | connects the panel button to the BMS key-switch input. CHECK THE BOX FIRST - DALY ship a ready-made key switch with some units |
| [SP17 2-pin IP68 flange socket + mating plug](https://www.amazon.com/dp/B0CDH5R8P4) | 2 | ea | $13.20 | $26.40 | verified | HangTon SP17. THE LISTING IS A PAIR - male cable plug AND female panel socket - which matters, because the charger arrives with whatever connector its own maker fitted and something has to go on the end of its lead. 10 A and 500 V on the 2-pin against our 67.2 V 5 A, takes up to 2 mm2 / 14 AWG so our 16 is comfortable, cable OD 6-10 mm, threaded coupling, brass contacts with gold plating, PA66 shell / PPS insert, -40 to +85 C, 500 mating cycles. PLUG IT IN BEFORE YOU POWER THE CHARGER: the port is dead whenever the BMS is off, and this board is already built that way round. THE SCREW CAP IS THE REASON THIS CONNECTOR IS HERE - CONFIRM IT IS IN THE BOX. Renhotec's SP17 page says sealing caps are AVAILABLE for both the cable and panel halves, which is not the same as included. This port is the lowest unrated opening into the module and it sits unmated every ride; if no cap ships, source one before the board does. FLANGE PITCH IS UNVERIFIED. The standard SP17 flange is a TWO-hole one - four is the EW-LP16 pattern, a different connector - and the 22 mm centres this model uses have never been found on a drawing. They go into a PRINTED wall, so order this early and measure it before the module shell prints at step 3 |
| [M3 heat-set insert kit, 361 pc](https://www.amazon.com/dp/B0G8JLX1HR) | 1 | kit | $13.98 | $13.98 | verified | covers the port flange (4 sets, 2 a port on a 22 mm square) and the nose cone. The kit's screws are PLAIN STEEL - buy M3 x 8 A4 separately for the flange, which lives in the wet cavity |
| [M3 x 8 A4 stainless, 10 pk](https://www.amazon.com/dp/B07DVMFMJZ) | 1 | pk | $6.76 | $6.76 | verified | 4 needed. The kit's screws are not stainless and this joint is submerged |
| **subtotal** | | | | **$460.99** | | |

## 9  Electrical

| Item | Qty | Unit | Unit $ | Ext $ | | Note |
|---|---:|---|---:|---:|---|---|
| [Silica gel, indicating, 50 g per module](https://www.amazon.com/dp/B0DSBCXHT3) | 1 | pk | $13.99 | $13.99 | estimate | ~40 g is a season at 50 breathing cycles; a token sachet is worth about six. Bake it dry when the indicator turns |
| [Flipsky 65161 120KV motor](https://flipsky.net/products/brushless-motor-sensorless-amphibious-fully-waterproof-motor-65161-120kv-100kv-6000w-for-efoil-ejet-boards-ebike-electric-surfboard) | 2 | ea | $298.00 | $596.00 | verified |  |
| [Flipsky 75200 Pro V2 ESC](https://flipsky.net/products/flipsky-75200-pro-v2-0-with-aluminum-pcb-based-on-vesc-for-electric-skateboard-electric-scooter-ebike-speed-controller) | 2 | ea | $150.00 | $300.00 | verified |  |
| [Thermal pad 1 mm non-conductive, 100 x 100](https://www.amazon.com/dp/B0GTLRJJGT) | 1 | ea | $9.99 | $9.99 | verified | 15.8 W/mK. One 100 x 100 sheet cuts both boards' baseplates. The ESC PCB face goes DOWN onto the floor, same as V1 did onto its alu bottom plate |
| [Flipsky VX3 remote](https://flipsky.net/products/flipsky-fully-waterproof-remote-vx3-controller-for-efoil-esurf-esk8) | 2 | ea | $71.00 | $142.00 | verified |  |
| [DALY Smart BMS Li-ion 16S 60V 150A](https://www.amazon.com/dp/B0CXXFQT9S) | 2 | ea | $147.70 | $295.40 | verified | batteryint.com; confirm it is <= 164 x 66 x 21 mm |
| [Charger 67.2 V 5 A, 16S  (NOT 58.8 V)](https://www.amazon.com/dp/B0DK6FTB1P) | 2 | ea | $45.99 | $91.98 | verified | Amazon B0DK6FTB1P, aluminium case + fan |
| [BAK N21700CG-50, 130-cell case (BatteryHookup)](https://batteryhookup.com/products/new-3-6v-5000mah-bak-n21700cg-50-2170-lithium-ion-cells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) | 1 | case | $260.00 | $260.00 | verified | new overstock |
| [BAK N21700CG-50 singles, spares](https://batteryhookup.com/products/new-3-6v-5000mah-bak-n21700cg-50-2170-lithium-ion-cells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) | 15 | ea | $2.50 | $37.50 | verified | 7% margin on a spot-welded pack |
| 21700 cells already on hand | 128 | ea | $0.00 | $0.00 | on hand |  |
| [Pure nickel 0.2 x 10 mm, 5 m roll](https://www.amazon.com/dp/B0961Q1VVR) | 3 | roll | $14.99 | $44.97 | verified | 6.9 m a board derived from the pack, not guessed. YOU ALREADY OWN 3 ROLLS (SUIDI, ordered Apr 16 x2 and May 6) - check the drawer before buying more. There is also a 5 m roll of 0.2 x 27 mm uxcell from Apr 12: too wide for bridges, but it is the right stock for the two terminal collectors and for doubling the edges without stacking two thin layers |
| [21700 cell holder, 1x2 brick, 50 pk](https://www.amazon.com/dp/B092PSRGZ6) | 6 | pk | $9.99 | $59.94 | verified | 512 cell positions across both boards, 2 per brick = 256 bricks. THROUGH-HOLE spacers, so they add no height - they locate the cells and set the pitch. ~22.5 mm against the model's 24, which leaves the real pack smaller than the cavity is cut for |
| [ANL 150 A fuse + holder](https://www.amazon.com/dp/B0B6ZHJR7D) | 2 | ea | $9.99 | $19.98 | verified | in the NEGATIVE leg, between BMS P- and the ESC - that is where V1 ran it and it is the node the charge negative branches from too |
| [Inline 10 A fuse + holder, charge lead](https://www.amazon.com/dp/B0F2YXV41Q) | 1 | pk | $7.59 | $7.59 | verified | at SPLIT A on the charge positive. The ANL is sized for the motor and cannot protect 16 AWG |
| [8 AWG silicone, 10 ft red + 10 ft black](https://www.amazon.com/dp/B0BYJRDT19) | 1 | pk | $21.99 | $21.99 | verified | one pack covers BOTH boards - the longest run in the module is the 278 mm ESC-to-fuse, so 10 ft a side is already 10x what the runs need. Motor supplies its own phase leads + bullets. Amazon 8 AWG 10+10 spans $18.88-$23.99; the 25 ft pack at $49.99 was buying 40 ft of wire to use about 3 |
| [PVC pack wrap, 200 mm lay-flat](https://www.amazon.com/dp/B09SVFL33L) | 1 | roll | $13.99 | $13.99 | verified | wide enough to sleeve a 16S brick; one roll does both |
| [Kapton tape, pack insulation](https://www.amazon.com/dp/B006ZFQNT6) | 1 | roll | $8.25 | $8.25 | estimate |  |
| **subtotal** | | | | **$1,923.57** | | |

## 8  Mast hardpoint

| Item | Qty | Unit | Unit $ | Ext $ | | Note |
|---|---:|---|---:|---:|---|---|
| [M6 x 1.0 tap + 5.0 mm drill set](https://www.amazon.com/dp/B0GSG4FGYW) | 1 | set | $9.99 | $9.99 | verified | 8 blind holes |
| [M6 x 1.0 BOTTOMING tap, 4-flute](https://www.amazon.com/s?k=Drill+America+M6+x+1.0+HSS+4-Flute+Bottoming+Tap) | 1 | ea | $8.78 | $8.78 | verified | the one that actually matters - blind at 10 mm in a 12.7 plate, and the taper tap in the set above cannot reach the bottom |
| [M6 x 22 A4 countersunk DIN7991, mast screws](https://www.amazon.com/dp/B01N3QSKHO) | 2 | pk | $6.49 | $12.98 | estimate | 8 needed, 4 a board, 5 to a pack. NO WASHERS - straight into their countersink; the cup washers in Gong's kit are a conical seat for mounting to a FLAT surface and belong to the US-box configuration, and anything under the head would eat into the 10 mm of engagement. DIN7991 90 deg head to match Gong's countersink - CHECK THE ANGLE against the real plate before ordering, it is the one thing about their part still unmeasured. A4-70 deliberately, not A4-80: our tapped 6061 is 1.42x this screw and the failure belongs on the part you can replace. TEF-GEL EVERY ONE - alu plate, stainless screw, wet joint |
| [Ultra Tef-Gel, galvanic barrier](https://www.amazon.com/dp/B01606TCAG) | 1 | ea | $39.00 | $39.00 | verified | every mast bolt, every time it goes back in. DEARER than the $22 this was carried at - and do not reach for the small tube to save it: the 3cc syringe is $31.51, so it is 80% of the price for a fraction of the gel |
| **subtotal** | | | | **$70.75** | | |
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

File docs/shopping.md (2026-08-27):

# Shopping list

Generated by `model/bom.py` - do not edit by hand.

Grouped by where you buy it rather than by what it does, because that is the order you actually place orders in. Quantities are for **2 boards**.

| Supplier | Lines | $ |
|---|---:|---:|
| Amazon | 116 | $3,668.86 |
| Gong | 1 | $1,404.00 |
| Flipsky | 3 | $1,038.00 |
| Not a purchase - tax and freight | 3 | $846.71 |
| BatteryHookup | 2 | $297.50 |
| Fiberglass Supply | 3 | $253.38 |
| Home Depot / hardware | 4 | $188.43 |
| Maker Shop Boise | 1 | $150.00 |
| Speedy Metals | 1 | $88.92 |
| Home Depot | 1 | $69.00 |
| Easy Composites | 1 | $52.00 |
| Branom / RS | 2 | $36.00 |
| **TOTAL** | | **$8,092.80** |

## Amazon

https://www.amazon.com

| Item | Qty | Unit | Ext | Price | Note |
|---|---:|---|---:|---|---|
| [TotalBoat 5:1 gallon kit, slow hardener](https://www.amazon.com/dp/B00HR8515C) | 2 | kit | $299.98 | **verified** | 2.51 m2 laminate = 4.8 kg mixed = 1 kit/board |
| [DALY Smart BMS Li-ion 16S 60V 150A](https://www.amazon.com/dp/B0CXXFQT9S) | 2 | ea | $295.40 | **verified** | batteryint.com; confirm it is <= 164 x 66 x 21 mm |
| [Peel ply, 60in](https://www.amazon.com/dp/B0H5JTMTZ3) | 6 | yd | $113.94 | **verified** | was only in the starter kit, and one kit's worth does not cover 6.12 m2 of part |
| [TotalBoat Wet Edge topside paint, colour](https://www.amazon.com/dp/B00HQP5D9A) | 2 | kit | $107.98 | **verified** | one-part polyurethane, quart |
| [Charger 67.2 V 5 A, 16S  (NOT 58.8 V)](https://www.amazon.com/dp/B0DK6FTB1P) | 2 | ea | $91.98 | **verified** | Amazon B0DK6FTB1P, aluminium case + fan |
| [TotalBoat TotalFair epoxy fairing compound](https://www.amazon.com/dp/B00S9RBWIA) | 2 | kit | $91.98 | **verified** | smallest kit, one per board |
| [Breather / bleeder cloth](https://www.amazon.com/dp/B015NM0B8K) | 6 | yd | $83.70 | **verified** | $13.95/yd cut; a 5 yd roll at $59.99 is $12.00/yd if you would rather buy the roll |
| [1/2 in spiral, 3 in cutting length - cavity wall](https://www.amazon.com/dp/B0BTY16K5P) | 1 | ea | $82.99 | **verified** | 76.2 mm of FLUTE - the only reach found that clears the 71.6 mm cavity wall in one pass. It is a COMPRESSION b |
| [1708 biax, 50in x 10 yd roll](https://www.amazon.com/dp/B07RJWHPKG) | 1 | roll | $79.95 | **verified** | 6 yd needed across both boards; $8.00/yd against Fibre Glast's $12.50 and no freight |
| [Vac bag film, 5 yd](https://www.amazon.com/dp/B079MBL5TX) | 3 | roll | $74.85 | **verified** | 3.06 m2 a hull session; 2 hulls + 4 lids + a practice piece + one re-do. Single-use on the hull, reusable on f |
| [ASA filament, printed module shell](https://www.amazon.com/dp/B09DKPYYBP) | 3 | kg | $73.47 | **verified** | 4 L-pieces/board, ~1.13 kg of part + supports and brim; largest piece 226 x 146 fits the A1 bed |
| [1/2 in O-flute up-spiral, foam roughing](https://www.amazon.com/dp/B001J9I6D4) | 1 | ea | $66.05 | **verified** | Freud 73-214, 1/2 in shank. SINGLE flute for chip clearance - EPS chips are bulky and a 2- or 3-flute packs th |
| [5052 1/8in x 12 x 24, 2-pack - module floors](https://www.amazon.com/dp/B0D3TH4TTC) | 1 | pk | $61.99 | **verified** | your Apr 2026 receipt (MorningRo/Huaiian). One sheet is one floor, so this pack does both boards |
| [21700 cell holder, 1x2 brick, 50 pk](https://www.amazon.com/dp/B092PSRGZ6) | 6 | pk | $59.94 | **verified** | 512 cell positions across both boards, 2 per brick = 256 bricks. THROUGH-HOLE spacers, so they add no height - |
| [TotalBoat 5:1 quart kit, fillets and bonding](https://www.amazon.com/dp/B00HR8517A) | 1 | kit | $58.99 | **verified** |  |
| [VECOTOOLS 4.5 CFM single-stage pump, oil incl.](https://www.amazon.com/dp/B0GZVLP3PL) | 1 | ea | $57.99 | **verified** | your listing, ASIN B0GZVLP3PL. Was a $139.99 Pittsburgh 2-stage plus $15 of oil - $97 for ultimate vacuum we m |
| [FOCEAN EVA deck sheet 2400 x 600 x 5.8](https://www.amazon.com/dp/B0BTLW75FL) | 1 | sheet | $54.14 | **verified** | 3 pieces a board - aft of the hatch, forward of it, and one on the lid - using 818 mm of the 2400 roll each. S |
| [ASA filament, printed rim ring](https://www.amazon.com/dp/B09DKPYYBP) | 2 | kg | $48.98 | **verified** | 6 dovetailed pieces/board at ~90% infill, 710 g of part each; PRINT SEAL FACE DOWN - the bed is flatter than a |
| [TotalBoat Premium Marine Topside Primer](https://www.amazon.com/dp/B00HS4YY7G) | 1 | kit | $46.99 | **verified** | one covers both |
| [Pure nickel 0.2 x 10 mm, 5 m roll](https://www.amazon.com/dp/B0961Q1VVR) | 3 | roll | $44.97 | **verified** | 6.9 m a board derived from the pack, not guessed. YOU ALREADY OWN 3 ROLLS (SUIDI, ordered Apr 16 x2 and May 6) |
| [1/2 in ball nose, finishing pass](https://www.amazon.com/dp/B00KZM3GSG) | 1 | ea | $41.95 | **verified** | 1/2 in shank. ONLY if the makerspace does not supply tooling |
| [Hydraulic lug crimper, 10 ton, 12-2/0 AWG](https://www.amazon.com/dp/B0CFV249X3) | 1 | ea | $39.99 | **verified** | one-time; this is what replaces soldering XT150s |
| [Folding sawhorses, pair, 700 lb](https://www.amazon.com/dp/B0G4CH7SKB) | 1 | pair | $39.99 | **verified** | ~30 in high. Racks buy height for planing, and this core comes machined - so they buy nothing here |
| [E-glass 6 oz, 50in x 12ft, 2-pack](https://www.amazon.com/dp/B0CQY5KX84) | 2 | pack | $39.98 | **verified** | your receipt |
| [Sealant tape, 50 ft roll](https://www.amazon.com/dp/B0GF25BPN6) | 2 | roll | $39.98 | **verified** | 31 m of bag perimeter across the project. 2 x 50 ft at $19.99 replaced 4 x 25 ft at $12 - same tape, fewer joi |
| [1/4 in composite bit - lid profiles](https://www.amazon.com/dp/B00IDEOSXU) | 1 | ea | $39.95 | estimate | Amana 46094, ZrN-coated solid carbide, ground for fibreglass and phenolic rather than wood. 19 mm of cutting h |
| [Bag connector w/ ball valve, 1/4 in QD](https://www.amazon.com/dp/B0FSKGGL8H) | 2 | ea | $39.18 | **verified** | THE BALL VALVE IS THE POINT: shut it and the bag is isolated from the pump, so leak-down is a real measurement |
| [Ultra Tef-Gel, galvanic barrier](https://www.amazon.com/dp/B01606TCAG) | 1 | ea | $39.00 | **verified** | every mast bolt, every time it goes back in. DEARER than the $22 this was carried at - and do not reach for th |
| [3M 60923 organic vapour / acid gas P100, pair](https://www.amazon.com/dp/B00AEFCKKY) | 2 | pr | $35.98 | **verified** | $18.39/pr on Amazon against $31.49 at envirosafetyproducts. Cartridges EXPIRE - buy these near the layup, not  |
| [Solid silicone cord, 3 mm round - BOTH seals](https://www.amazon.com/dp/B096N67R2D) | 2 | pc | $35.18 | **verified** | 10 ft (3.05 m) pieces, 70A. Buy long - splice on a straight run, never a corner |
| [Hollow punch set 3/16-1-3/8in, for the O30 bung](https://www.amazon.com/dp/B07PQYRG9K) | 1 | set | $32.99 | estimate | the existing set stops at 1/2 in and the disc is O30.0 - the 1-3/16 in punch is 30.16, near enough in rubber.  |
| [M12 IP68 momentary panel button](https://www.amazon.com/dp/B0FPQP7CP9) | 1 | ea | $32.65 | **verified** | 1 on hand; this line buys the second board's |
| [IP68 M25 inline housing, 5 pk](https://www.amazon.com/dp/B0DPKM5HF7) | 2 | pk | $31.96 | **verified** | 3 per board, one per phase, 2 spare. M25 bodies take 4-14 mm cable against our 6.5 mm 8 AWG, so the size class |
| [Coiled ankle leash](https://www.amazon.com/dp/B096VL3DHV) | 2 | ea | $29.98 | **verified** | you trust the remote failsafe; this is so the board stays with you |
| [Kayak/board grab handle, 2 pk + screws](https://www.amazon.com/dp/B0FBW3XT5D) | 3 | pk | $29.97 | **verified** | 3 a board: 2 on the rails into the 6061 strip, 1 on the module. ONE HOLE PER STRAP END - so one bolt per pad,  |
| [Sikaflex-292 marine structural PU](https://www.amazon.com/dp/B008F8VYMM) | 1 | tube | $28.99 | **verified** | ~6-8 MPa vs 4200's ~2. Fillet BOTH sides of the joint - on a flexible bond the fillets are what stop it peelin |
| [Sika Aktivator-PRO 250 ml + daubers](https://www.amazon.com/dp/B0D9KTLC1M) | 1 | ea | $28.95 | **verified** | abrade + solvent wipe + activate the 5052; scuff the ASA. Aktivator-205 is DISCONTINUED - Aktivator-PRO replac |
| [Nitrile gloves 6 mil, 100 pk](https://www.amazon.com/dp/B0C3SSXL4K) | 2 | box | $28.88 | **verified** |  |
| [M4 x 12 A4 socket cap DIN912, 10 pk](https://www.amazon.com/dp/B07DVPC7HT) | 4 | pk | $28.40 | **verified** | 36 needed. A4/316 again - the $0.09/ea listings are all A2/304 |
| [TotalBoat 5:1 FAST hardener 6 oz, cold days](https://www.amazon.com/dp/B00HRHA59K) | 1 | ea | $27.99 | **verified** | min 40-45 F against slow's 60. In a cold shop this is the one that cures, and the cold gives the pot life back |
| [Rosin paper roll, floor and bench](https://www.amazon.com/dp/B0FXJDFW2B) | 1 | roll | $27.95 | estimate | absorbs instead of pooling. This is the actual upgrade over a tarp, and it is $24 |
| [SP17 2-pin IP68 flange socket + mating plug](https://www.amazon.com/dp/B0CDH5R8P4) | 2 | ea | $26.40 | **verified** | HangTon SP17. THE LISTING IS A PAIR - male cable plug AND female panel socket - which matters, because the cha |
| [3M Fastbond 1077 water-based, CNC hold-down](https://www.amazon.com/dp/B0GRSV587N) | 1 | ea | $26.02 | **verified** | WATER-BASED because the blank is EPS - solvent sprays like Super 77 eat polystyrene. Foam is taped/tacked down |
| [PETG filament 1 kg, mast clamp set](https://www.amazon.com/dp/B0D41Y3WWZ) | 2 | kg | $25.98 | **verified** | 4 STEP files; 0.6 nozzle, 5 perims, 40% infill |
| [PETG for props, 4-5 spares per board](https://www.amazon.com/dp/B0D41Y3WWZ) | 2 | kg | $25.98 | **verified** | 0.4 nozzle, 100% infill; balance-check on a bolt, then epoxy-coat - V1 skipped the coat and layer lines cost d |
| [1/4 in torque wrench, 10-50 in-lb](https://www.amazon.com/dp/B0D7PWP7YF) | 1 | ea | $25.97 | **verified** | 1.1-5.6 Nm. RANGE MATTERS: our hatch spec is 1.2 Nm = 10.6 in-lb, which is BELOW the 20 in-lb floor of the com |
| [Transfer screw set M3-M6](https://www.amazon.com/dp/B01IUBRSLO) | 1 | set | $24.99 | estimate | RECOVERY, not method - the CNC cuts all 12 hatch holes in one setup and the pattern aligns as one rigid body.  |
| [Transfer punch set, metric 1-13 mm](https://www.amazon.com/dp/B005379HJA) | 1 | set | $24.99 | estimate | the 9 mm punch is a slip fit in Gong's own clearance holes and marks true centre within a few hundredths. A 6. |
| [Test cap + tubing, module leak test](https://www.amazon.com/dp/B0DPWRP6FR) | 1 | set | $22.99 | estimate | PROVE THE MODULE BEFORE THE CELLS GO IN, and prove it the way the failure actually happens: run one of the kit |
| [8 AWG silicone, 10 ft red + 10 ft black](https://www.amazon.com/dp/B0BYJRDT19) | 1 | pk | $21.99 | **verified** | one pack covers BOTH boards - the longest run in the module is the 278 mm ESC-to-fuse, so 10 ft a side is alre |
| [Compression flush-trim bit, 1/4 in shank, lid masters](https://www.amazon.com/dp/B0GDDXH1YH) | 1 | ea | $21.99 | estimate | SHARPRO, bottom bearing, 31.75 mm of cutting length against a 15.2 mm lid - one pass. COMPRESSION on purpose:  |
| [Longboard PSA sandpaper 120-180 grit, 20 yd roll](https://www.amazon.com/dp/B001AVC8ZI) | 1 | roll | $20.99 | **verified** | after 80 has the shape right |
| [Flex longboard sander, 16-1/2 x 2-3/4](https://www.amazon.com/dp/B0CPR1CGQV) | 1 | ea | $19.99 | **verified** | adjustable radius, hook-and-loop + PSA |
| [ANL 150 A fuse + holder](https://www.amazon.com/dp/B0B6ZHJR7D) | 2 | ea | $19.98 | **verified** | in the NEGATIVE leg, between BMS P- and the ESC - that is where V1 ran it and it is the node the charge negati |
| [Cable ties, lacing, adhesive mounts](https://www.amazon.com/dp/B08RMS5H25) | 2 | set | $19.98 | estimate |  |
| [M5 x 250 threaded rod, 4 pk (cut to ~171 mm)](https://www.amazon.com/dp/B0CMZR9L1Y) | 2 | pk | $19.98 | **verified** | a 4-pack is exactly one board's worth. Dry-assemble and mark before cutting |
| [8 AWG marine ring lugs, 20 pk](https://www.amazon.com/dp/B0CWGXB4NB) | 2 | pk | $19.98 | **verified** | 28 needed; on M6 studs - nothing to solder |
| [Release wax / PVA for the cavity caul](https://www.amazon.com/dp/B0HB5VXRY1) | 1 | set | $19.90 | estimate |  |
| Carbide-tipped drills 5.0 + 5.6 mm, the lid bolt holes | 1 | pair | $18.00 | estimate | 58 holes across both boards through cured laminate. Carbide-tipped, not HSS: glass does not blunt a drill so m |
| [3M 4200 FC 3 oz tube, skim over the bung](https://www.amazon.com/dp/B00MJ9K78A) | 1 | tube | $17.99 | **verified** | does both boards; 4200 NOT 5200 - 5200 never comes out. NOT A BARRIER in the channel any more - the blocker is |
| [Thermometer / hygrometer, 2 pk](https://www.amazon.com/dp/B086PC5962) | 1 | pk | $17.99 | estimate | one in the shop, one by the part. Slow needs 60 F, fast needs 40-45, and below ~35 nothing cures at all |
| [Chip brushes 2 in, 36 pk](https://www.amazon.com/dp/B078XJ2DCJ) | 1 | pk | $17.99 | **verified** | disposable, 2-4 a session across 6 sessions. The 12 pk at $7.19 is dearer per brush and runs out mid-build |
| [Laminating bubble roller kit, 4 pc](https://www.amazon.com/dp/B07FCLTHY6) | 1 | kit | $17.99 | **verified** |  |
| [Paste wax, releasing the groove filler](https://www.amazon.com/dp/B0GVCGHZFR) | 1 | ea | $16.99 | estimate | the filler must NOT bond - it comes back out after the glass goes over it |
| [Neoprene sheet 1/2in, wire bung](https://www.amazon.com/dp/B01LX83X9H) | 1 | sheet | $16.00 | estimate | 1/2 in. The blocker takes 4 mm off the top of the plate's bore, so the bung has 8.7 of it - and a 12.7 disc in |
| [M5 x 25 button head TORX TX25, 25 pk](https://www.amazon.com/dp/B08BZJPJTK) | 1 | pk | $15.99 | estimate | 24 needed of 25. TX25 drive. ISO 7380-2 flanged button; the model draws the plain O9.5 x 2.75 high, which is w |
| [Adjustable hand sanding block](https://www.amazon.com/dp/B0D4LNDYXD) | 1 | ea | $15.99 | **verified** | rails, nose, tail and anywhere the longboard will not reach |
| [Longboard PSA sandpaper 80 grit, 20 yd roll](https://www.amazon.com/dp/B0CQ7CVGK6) | 1 | roll | $15.99 | **verified** | 2-3/4 in, self-adhesive, fits the longboard above. 80 is the fairing grit - it cuts fair, it does not finish |
| [Solid silicone cord, 1/8 in (3.175 mm) - the spare size](https://www.amazon.com/dp/B00QVB0KE8) | 1 | pc | $15.39 | **verified** | 10 ft piece, 70A. Fitted ONLY if the routed groove measures deep. Gives 24% squeeze at the nominal 2.4 depth a |
| [16 AWG silicone, 6 colours x 5 ft](https://www.amazon.com/dp/B089CPH72F) | 1 | kit | $14.49 | **verified** | charge port and power button runs are short; one kit does both boards and the colours keep them straight |
| [M4 x 12.7 LONG brass heat-set insert, 50 pc](https://www.amazon.com/dp/B07473ZV71) | 1 | pack | $14.00 | estimate | 36 needed; 5.6 mm printed pilot |
| [Silica gel, indicating, 50 g per module](https://www.amazon.com/dp/B0DSBCXHT3) | 1 | pk | $13.99 | estimate | ~40 g is a season at 50 breathing cycles; a token sachet is worth about six. Bake it dry when the indicator tu |
| [Closed-cell sponge EPDM 1/8in, module lid gasket](https://www.amazon.com/dp/B07FWQM34V) | 1 | roll | $13.99 | **verified** | blank is 443 x 314 mm a board; the roll is 432 wide so it nests across, and 2032 long does both with room over |
| [PVC pack wrap, 200 mm lay-flat](https://www.amazon.com/dp/B09SVFL33L) | 1 | roll | $13.99 | **verified** | wide enough to sleeve a 16S brick; one roll does both |
| [Adhesive-lined heat shrink 3:1, 400 pc kit](https://www.amazon.com/dp/B0BVVMCY86) | 1 | kit | $13.99 | **verified** | marine grade, glue-lined - plain heat shrink over a joint in a wet cavity is decoration |
| [M3 heat-set insert kit, 361 pc](https://www.amazon.com/dp/B0G8JLX1HR) | 1 | kit | $13.98 | **verified** | covers the port flange (4 sets, 2 a port on a 22 mm square) and the nose cone. The kit's screws are PLAIN STEE |
| [PL300 / Gorilla Glue, layer glue-up](https://www.amazon.com/dp/B0009XEGVC) | 2 | tube | $13.18 | estimate |  |
| [M6 penny washer O18 A4 DIN9021](https://www.amazon.com/dp/B0DB8RBY3N) | 1 | pk | $12.99 | estimate | 58 needed - TWO PER BOLT, one captive under the nut and one UNDER THE HEAD. M6 size on an M5 bolt: the 0.7 mm  |
| [Water-ingress alarm, 2 pk](https://www.amazon.com/dp/B09DCMCB8D) | 1 | pk | $12.99 | **verified** | Geevon 100 dB pucks - the 2-pack covers BOTH boards. Put the SENSOR on the module floor in the lowest corner,  |
| [5.5 mm gold bullets, 20 pair](https://www.amazon.com/dp/B096DJKR5Y) | 1 | pk | $12.99 | **verified** | 3 pair a board, so one pack covers both with spares. Motor pigtails arrive with their own |
| [Roll pin assortment M1.5-M6, 220 pc](https://www.amazon.com/dp/B09MPWY8L4) | 1 | kit | $12.99 | **verified** | 4 needed. An ASSORTMENT on purpose: the note says MEASURE the shaft cross-hole rather than trust the 4 mm figu |
| [Dowel pins + drill, two-sided registration](https://www.amazon.com/dp/B0GS2R3F5G) | 1 | set | $12.99 | estimate |  |
| [M6 x 22 A4 countersunk DIN7991, mast screws](https://www.amazon.com/dp/B01N3QSKHO) | 2 | pk | $12.98 | estimate | 8 needed, 4 a board, 5 to a pack. NO WASHERS - straight into their countersink; the cup washers in Gong's kit  |
| [M6 x 12.7 brass heat-set insert, 50 pc](https://www.amazon.com/dp/B077PGD6X2) | 1 | pk | $12.00 | estimate | 4 needed, module handle pads; 8.2 mm printed pilot, same as the model's cut. LOCTITE the bolts - the pedestal  |
| [Vacuum hose + hose clamps](https://www.amazon.com/dp/B0FH52FT4G) | 1 | set | $11.61 | estimate | 1/2 in tubing pump-to-bag plus clamps; the other half of what the deleted kit was actually carrying |
| [Vacuum gauge, -30 inHg, 1/4 NPT, glycerin](https://www.amazon.com/dp/B00VQSOZFQ) | 1 | ea | $10.50 | **verified** | reads the BAG, not the pump - tee it in at the bag end. The regulator sets the level; this is how you know it  |
| [Gebildet PG11 gland, M18x1.5, 30 pk](https://www.amazon.com/dp/B0B8NJR62L) | 1 | pk | $9.99 | **verified** | your listing: M18x1.5 thread (matches the 18.5 hole) and 5-10 mm cable, against our 6.5 mm 8 AWG. 6 needed of  |
| [M6 x 1.0 tap + 5.0 mm drill set](https://www.amazon.com/dp/B0GSG4FGYW) | 1 | set | $9.99 | **verified** | 8 blind holes |
| [Thermal pad 1 mm non-conductive, 100 x 100](https://www.amazon.com/dp/B0GTLRJJGT) | 1 | ea | $9.99 | **verified** | 15.8 W/mK. One 100 x 100 sheet cuts both boards' baseplates. The ESC PCB face goes DOWN onto the floor, same a |
| [Silicone grease for the seal cord](https://www.amazon.com/dp/B0BN82MJVK) | 1 | tube | $9.99 | estimate | stops the cord bonding to the lid in storage |
| [Fish tape / pull cord for the mast conduit](https://www.amazon.com/dp/B0FGCY7XPS) | 1 | ea | $9.99 | estimate |  |
| 1/4 to 1/8 in collet reducer, for the 2.5 mm groove cutter | 1 | ea | $9.99 | estimate | the P601 is a 1/4 in collet and the groove cutter is a 1/8 in shank. Cheap, and the alternative is a bit that  |
| [Plastic sheeting + masking tape, bench protection](https://www.amazon.com/dp/B0GF2BWRC6) | 1 | set | $9.99 | estimate |  |
| [M6 x 20 fender washer, 100 pk](https://www.amazon.com/dp/B0DPMPJW4H) | 1 | pk | $9.49 | **verified** | 8 needed |
| [M5 A4 hex nut DIN934, 50 pk - CAPTIVE in the ring](https://www.amazon.com/dp/B084HLMN7B) | 1 | pk | $9.19 | **verified** | 34 needed. Dropped in at a print pause at Z=6.0; steel thread, so a hatch that comes off every ride never wear |
| [Black epoxy pigment, marking the lid plugs](https://www.amazon.com/dp/B09NYDCXBQ) | 1 | ea | $8.99 | estimate | a few drops in the plug epoxy for both lids - 30 plugs a board and a 50 ml bottle is a lifetime. Not decoratio |
| [Dielectric grease, terminals](https://www.amazon.com/dp/B0D6R543V2) | 1 | tube | $8.99 | estimate |  |
| [M5 nyloc nut 316, 150 pk](https://www.amazon.com/dp/B0BP2T6Z4Q) | 1 | pk | $8.99 | **verified** | a separate pack from the washers above - they do not come together |
| [M8 nyloc nut 316, 30 pk - prop nut](https://www.amazon.com/dp/B0BP2R3YHY) | 1 | pk | $8.99 | **verified** | 2 needed. 316 not 304 - this one is permanently submerged. WASHER NOT INCLUDED, see below |
| [Pipe lagging or carpet, sawhorse padding](https://www.amazon.com/dp/B0CBYST37N) | 1 | set | $8.99 | estimate | bare sawhorse tops mark foam and wet laminate |
| [Wet/dry sandpaper assortment, 45 pc](https://www.amazon.com/dp/B0GHND351C) | 1 | pk | $8.99 | **verified** | 80-400 for detail and between primer coats |
| [M6 x 1.0 BOTTOMING tap, 4-flute](https://www.amazon.com/s?k=Drill+America+M6+x+1.0+HSS+4-Flute+Bottoming+Tap) | 1 | ea | $8.78 | **verified** | the one that actually matters - blind at 10 mm in a 12.7 plate, and the taper tap in the set above cannot reac |
| [Kapton tape, pack insulation](https://www.amazon.com/dp/B006ZFQNT6) | 1 | roll | $8.25 | estimate |  |
| [M6 x 16 A4 button head, 10 pk](https://www.amazon.com/dp/B07DVRLQTK) | 1 | pk | $8.06 | **verified** | 12 needed - 2 per rail handle into the 6061 strip, 2 into the module pads. Fender washer under every one: the  |
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

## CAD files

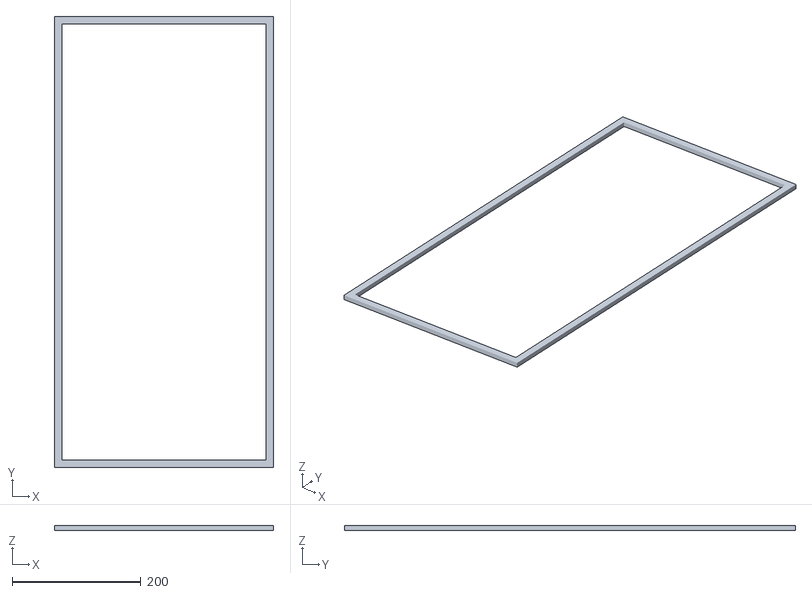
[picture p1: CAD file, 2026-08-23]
docs/v1/stl/Part Studio 1 - Main Lid Gasket.stl
340.7 x 701.9 x 7.60

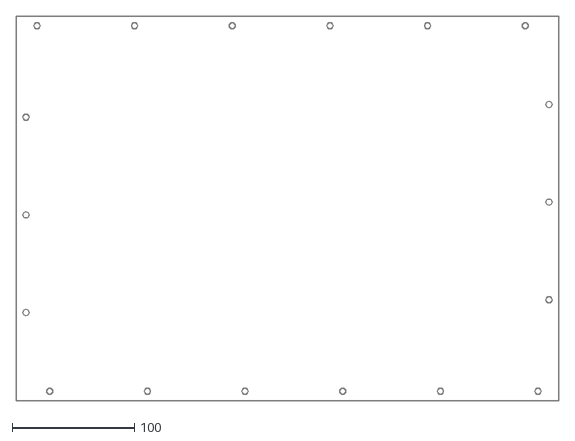
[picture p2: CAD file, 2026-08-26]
cnc/16_module_lid_guide.dxf
443.2 x 314.4

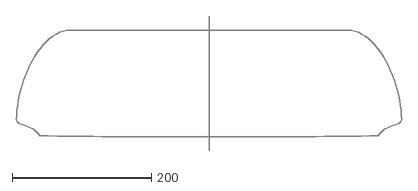
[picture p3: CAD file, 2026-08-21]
cnc/templates/T08_station_55.dxf
554.0 x 193.8

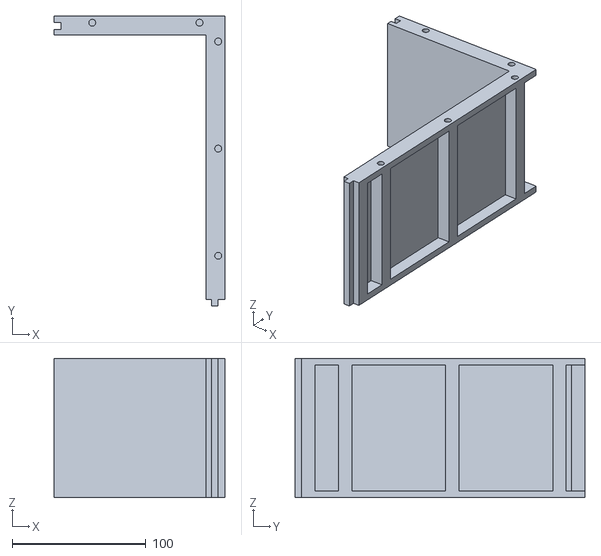
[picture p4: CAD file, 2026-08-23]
docs/v1/stl/Part Studio 1 - Battery Front Right Wall.stl
127.5 x 216.5 x 104.0

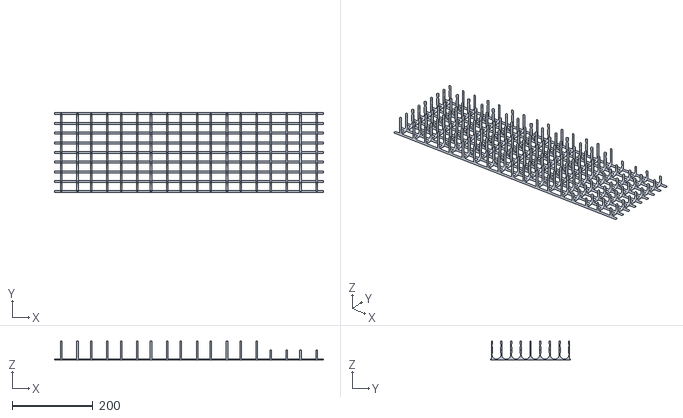
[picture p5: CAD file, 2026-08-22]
model/cell_holder.stl
666.0 x 197.0 x 46.8

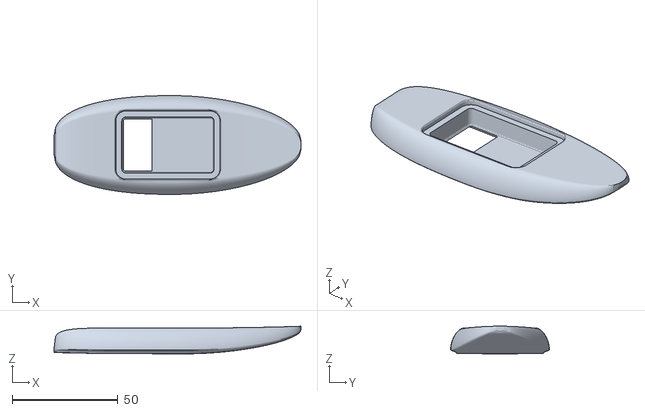
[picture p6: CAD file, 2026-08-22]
print/efoil_v2_hull_1-12.stl
116.7 x 46.7 x 13.0

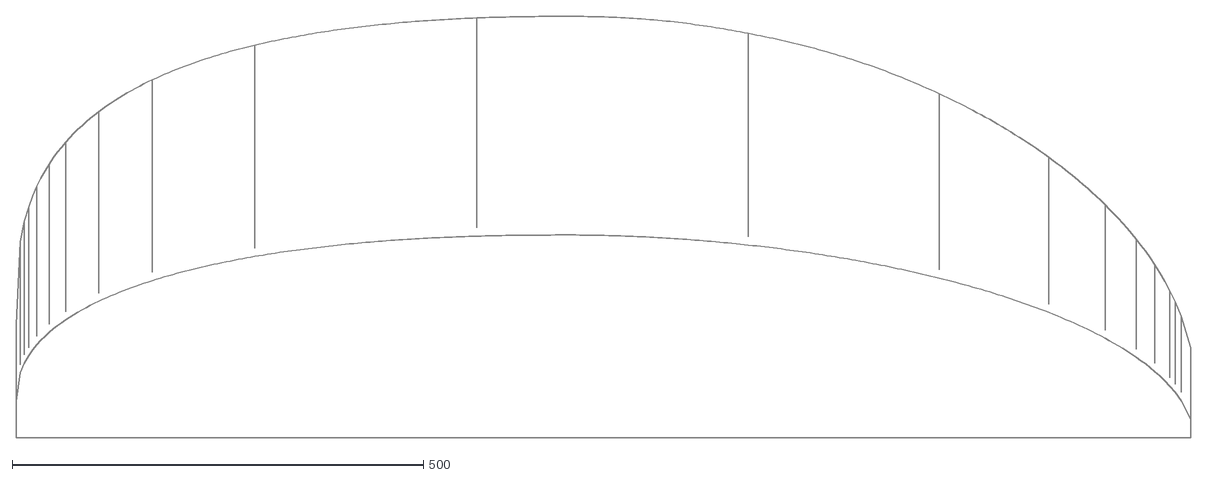
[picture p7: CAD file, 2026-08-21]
print/glass/bottom_ply.dxf
1428.0 x 512.2

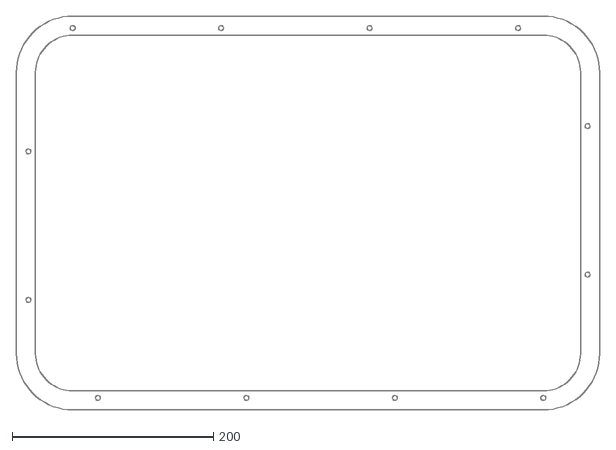
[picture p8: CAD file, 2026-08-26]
cnc/14_groove_guide.dxf
579.7 x 391.4

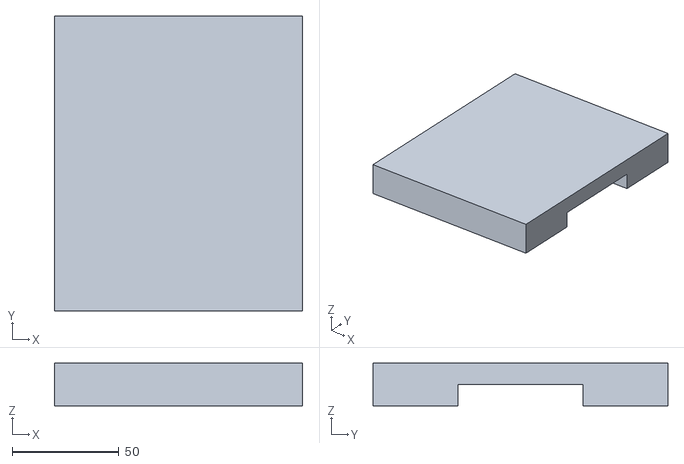
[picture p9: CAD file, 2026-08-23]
docs/v1/stl/Part Studio 1 - Esc Ecclosure bumpup.stl
116.5 x 138.5 x 20.0

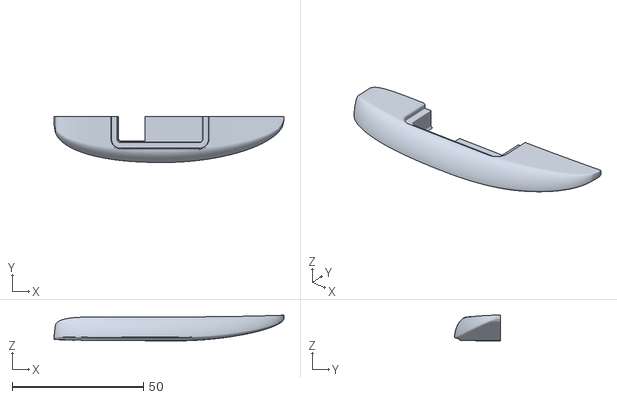
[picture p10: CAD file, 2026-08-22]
print/efoil_v2_hull_cutaway_1-16.stl
87.5 x 17.5 x 9.77

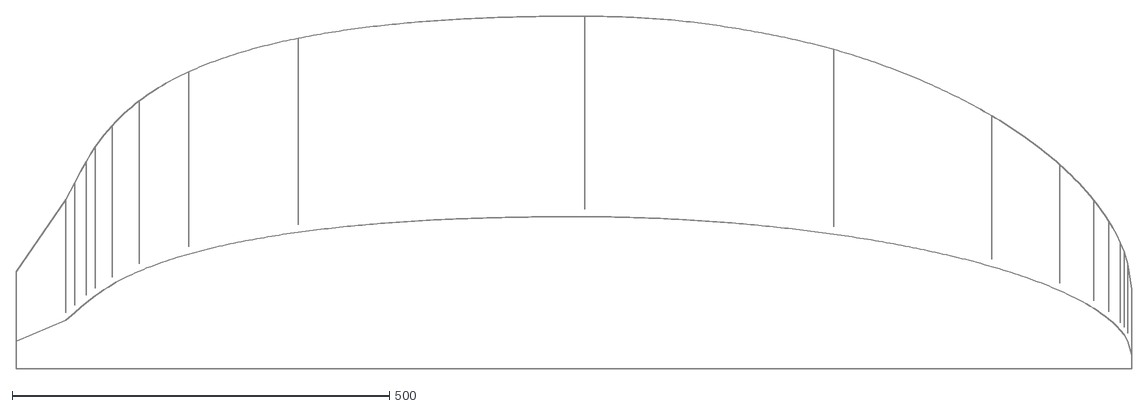
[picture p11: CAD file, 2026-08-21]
print/glass/deck_ply.dxf
1478.4 x 467.4

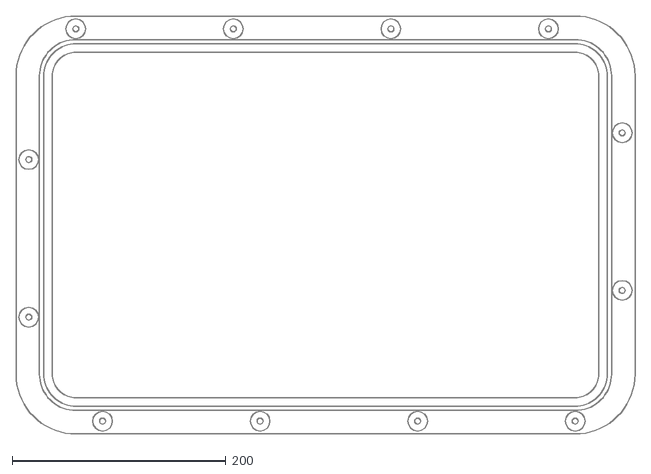
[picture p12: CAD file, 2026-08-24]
cnc/01_rim_ring.dxf
579.7 x 391.4

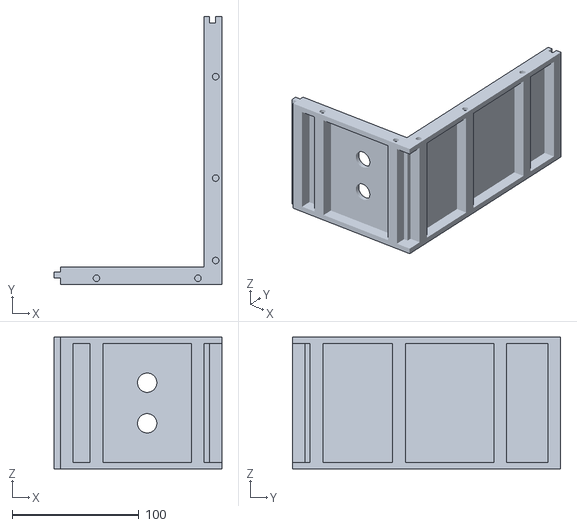
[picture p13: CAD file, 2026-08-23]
docs/v1/stl/Part Studio 1 - Battery Back Right Wall.stl
132.5 x 211.5 x 104.0

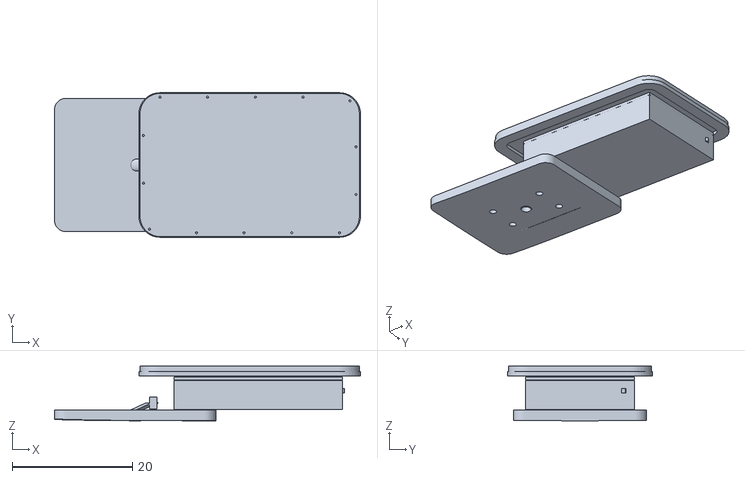
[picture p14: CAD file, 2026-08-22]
print/efoil_v2_internals_1-16.stl
51.0 x 24.1 x 9.15

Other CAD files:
model/efoil_v2_hull.stl
cnc/10_module_lid.dxf
docs/v1/stl/Part Studio 1 - Foam Board.stl
print/efoil_v2_hull_cutaway_1-20.stl
cnc/01c_handle_strip.dxf
cnc/03_hatch_lid_core.dxf
cnc/03b_lid_spreaders.dxf
cnc/04_module_floor.dxf
cnc/06_module_wall_end.dxf
cnc/11_module_lid_core.dxf
cnc/12_mast_plate.dxf
cnc/13_cavity_caul.dxf
cnc/15_deck_pad_nest.dxf
cnc/17_hatch_lid_master.dxf
docs/v1/stl/Part Studio 1 - BMS.stl
docs/v1/stl/Part Studio 1 - Battery Back Left Wall.stl
docs/v1/stl/Part Studio 1 - Battery Bottom Plate.stl
docs/v1/stl/Part Studio 1 - Battery Front Left Wall.stl
docs/v1/stl/Part Studio 1 - Battery Gasket (1).stl
docs/v1/stl/Part Studio 1 - Battery Gasket (2).stl
docs/v1/stl/Part Studio 1 - Battery Gasket (3).stl
docs/v1/stl/Part Studio 1 - Battery Gasket.stl
docs/v1/stl/Part Studio 1 - Battery Top Plate.stl
docs/v1/stl/Part Studio 1 - Battery.stl
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

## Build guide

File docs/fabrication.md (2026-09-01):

# Build guide — every step, in order

How this board actually gets made, start to finish. Each step says what you
do, what it needs finished first, and **exactly which BOM lines it consumes**.

- **Uses:** lines quote BOM item names verbatim. `model/check_build_guide.py`
  verifies every one still exists, so this file cannot quietly drift from
  [bom.md](bom.md) the way the old colour key drifted from the model.
- **Blocks on:** what must be done first. Anything with no blocker can start
  today.
- Step numbers are stable. Add with letters (`4a`) rather than renumbering.

Two boards are being built. Almost everything below is "×2" — the exceptions
are the shop kit, which is bought once, and the CNC session, which does both
cores in one booking.

---

> **Watch it first.** `model/animate_build.py` renders these steps as a
> two-minute animation straight out of the model — the CNC setups, the flip,
> the bonding order, the module going together and dropping in. Every frame is
> the real geometry, so if the animation and this file disagree, one of them
> has drifted and it is worth finding out which:
>
> ```
> blender -b model/efoil_v2.blend --python model/animate_build.py -- --res 1600
> ```

## The shape of the job

Three chains run in parallel and only meet at the end. **Start all three on
day one** — the board chain is the long one, and the other two are pure
waiting if you leave them late.

| Chain | What | Wall time | On the critical path? |
|---|---|---|---|
| **A — Board** | core → laminate → fair → paint | ~8 weekends | **Yes.** Everything else waits on it |
| **B — Printing** | rim rings, module shells, props, clamps | ~120 print hours | No, *if started first* |
| **C — Pack** | cells → weld → BMS → wiring | ~2 weekends | No |

The two things that will actually delay you are **not** in the shop:

1. **The foil ships from France** and US customs arrives *after* delivery as a
   courier invoice. Order it first.
2. **The makerspace has not confirmed it allows EPS.** If the answer is no,
   step 4 changes completely — see [Appendix C](#appendix-c--if-the-cnc-falls-through).

---

# Phase 0 — Before anything

### Step 1. Order the long-lead items

Everything else can wait a week. These cannot.

**Uses:** `Gong Foil Setup X-Over V3 Atmo Perf Series - XL, Alu 85` ·
`Gong shipping to Idaho, ONE order, both foils` ·
`BAK N21700CG-50, 130-cell case (BatteryHookup)` ·
`BAK N21700CG-50 singles, spares` ·
`Flipsky 65161 120KV motor` · `Flipsky 75200 Pro V2 ESC` ·
`Flipsky VX3 remote` · `DALY Smart BMS Li-ion 16S 60V 150A`

Both foils go in **one** Gong order — shipping is charged per order, not per
foil. Budget for import duty separately; it is not quoted at checkout.

### Step 2. Phone the makerspace — do not email

Email got no reply twice. **(208) 254-6151.** Ask, in this order:

1. **Will you allow EPS foam on the CNC?** Mess, static, clogs extraction.
   This one can stop the plan.
2. What is the clearance under the gantry? The split sequence needs ~110 mm,
   so this is now a nice-to-know rather than a blocker.
3. Which CAM do you use, and can I bring my own toolpaths?

**Uses:** `Maker Shop Boise Basic month`

Basic is **8 shop visits a month, not unlimited** — a budget, not a door key.
Unlimited is $250, a day pass $99. Month-to-month, 10 days notice to cancel.

### Step 3. Start the printers, and do not stop them

~120 hours of printing. Start now and it is never the thing you are waiting
for; start in week six and it is the only thing you are waiting for.

**Uses:** `ASA filament, printed rim ring` · `ASA filament, printed module shell` ·
`PETG filament 1 kg, mast clamp set` · `PETG for props, 4-5 spares per board` ·
`M5 A4 hex nut DIN934, 50 pk - CAPTIVE in the ring` ·
`M6 penny washer O18 A4 DIN9021`

Print order, longest first: module shells → rim rings → props → clamps.

**The rim ring prints seal-face DOWN.** The bed is flatter than any top
surface, and that face is the sealing land. **Pause at Z = 6.0 mm**, drop 12
M5 nuts and their washers into the pockets, resume. Get this wrong and the
hatch has no threads.

---

# Phase 1 — The core

### Step 4. Glue up two sub-stacks per board

Not one stack. **Four EPS layers become two 2-layer slabs**, because the
glued 4-layer stack is 203.2 mm and the gantry is 149.9 mm.

**Blocks on:** —
**Uses:** `EPS rigid foam 2in x 48in x 8ft (HD 202532856)` ·
`PL300 / Gorilla Glue, layer glue-up`

Four sheets cover both boards. Cut layers oversize to ~1420 × 580 — two nest
per 1219 × 2438 sheet. Glue **layers 1+2** and **layers 3+4** as separate
slabs, 101.6 mm each. Keep both faces flat; they are the machining datum.

> **Four layers, not three — but only just, and that is worth knowing.**
> Three sheets are 152.4 mm against a 153.7 mm envelope, so they miss by
> **1.3 mm**, and the miss lands on the rocker where there is no material to
> borrow. When this was decided the board was 153.8 thick and three sheets
> were 11.4 mm short; the board has slimmed since and nobody re-checked. It
> still points the same way. If it ever loses another 2 mm, re-open it — a
> whole sheet a board and an even 2+2 machining split ride on this.
> `blank_three_sheets_short_by_mm` tracks it now, so it cannot go stale again.

### Step 5. Machine the core — one booking, both boards

**Blocks on:** steps 2, 4
**Uses:** `1/2 in O-flute up-spiral, foam roughing` · `1/2 in ball nose, finishing pass` ·
`1/2 in spiral, 3 in cutting length - cavity wall` ·
`3M Fastbond 1077 water-based, CNC hold-down` · `Sacrificial MDF, CNC spoilboard` ·
`Dowel pins + drill, two-sided registration`

**Five setups, one flip, no cradle.** The full table is in
[cut-list.md](../cnc/cut-list.md); the short version:

| Piece | Setups | Cut |
|---|---|---|
| `Aft_Lower` | 2 | cavity lower half (top); rocker + mast pocket (bottom) — **the flip** |
| `Aft_Upper` | 1 | deck crown, cavity through, rim ledge, leash pocket |
| `Fwd_Lower` | 1 | rocker |
| `Fwd_Upper` | 1 | deck crown |

Every setup beds on a flat face, so **tape or vacuum down — never clamp from
the edges**, there is only 24.8 mm a side.

> **CUTTER REACH — two bits, and take both.** The deepest pocket is the
> cavity's lower half at **71.6 mm**, and the Freud O-flute has a *cutting*
> length of **31.8 mm** — that is flute, not overall.
>
> **That does not matter for roughing.** Z-level passes clear the whole
> pocket at every level, so by the time the tool is 71.6 mm down its shank is
> travelling through open air, not down a slot. The Freud roughs the lot.
>
> **It matters for the wall finish**, which is one pass down a finished wall
> with 12.7 mm of smooth shank rubbing EPS above the cutting edge. Foam has
> no strength to resist it but it does melt and glaze, and a glazed wall is a
> bond surface you cannot wet out. That is what the **3 in spiral** is in the
> BOM for: **76.2 mm of flute against 71.6 mm of wall.** It has been on the
> list all along; earlier drafts of this box told you to go buy one.

Water-based adhesive only. **Super 77 is solvent-based and dissolves EPS.**

### Step 6. Bond the core solid

**Blocks on:** step 5
**Uses:** `PL300 / Gorilla Glue, layer glue-up`

Mid-plane first — Lower to Upper, each side of the seam — which gives two
full-thickness halves you can handle on a bench. Then butt those at the
vertical seam (1030 mm). Dowel pins keep the halves registered.

### Step 7. Fit the hardpoints

**Blocks on:** step 6
**Uses:** `Divinycell H-80 3/4in quarter sheet 24x48, mast block + leash pad` ·
`6061-T651 1/2in x 12 x 18 - mast plates` · `M6 x 1.0 tap + 5.0 mm drill set` ·
`M6 x 1.0 BOTTOMING tap, 4-flute` · `Transfer punch set, metric 1-13 mm`

The CNC already cut the pockets. Bond the H-80 mast block and leash pad in,
flush.

**Then bond the 6061 plate into its pocket — and prep it first, because
epoxy does not grip bare aluminium.** This step had no instruction for the
plate at all, on the one part of the board that is buried, unreplaceable,
and sitting in wet foam for the rest of its life. The recipe is the one the
module floor already uses:

1. **Abrade every bonded face with 80 grit** — fresh, bright metal, no
   gloss left. Aluminium's oxide skin is what epoxy fails on.
2. **Solvent wipe** with acetone on a clean rag, and keep wiping until the
   rag comes up clean. Do not touch the faces with bare hands afterwards.
3. **Bond within the hour.** A fresh abrade oxidises fast; a plate prepped
   yesterday is a plate that needs prepping again.
4. Bed it in **thickened epoxy**, full contact, no voids — this is the
   pocket the mast's whole load goes into. Weight it flat and let it cure
   before the laminate goes over it.

> The four tapped holes stay **blind** through all of this. Nothing gets into
> them, nothing gets tapped until step 23, and the 2.7 mm of solid alu above
> them is what keeps the cavity dry.

> **Bed the wire blocker before the plate goes on.** A printed part: **Ø30.4 ×
> 4 body** that fills the top of the plate's bore, a **Ø23.6 × 12 spigot** up
> into the foam's, and a **22 × 7 slit** for the leads.
>
> **This is what gives the wire bung a stop that exists.** The bung is squeezed
> by the mast plate and something has to take that push. **Nothing is machined
> into the alu for it** — the plate keeps its one straight Ø30.8 bore. The
> dense block is simply **bored narrower, at Ø24**, and the ring of foam that
> leaves showing inside the plate's bore is what the blocker lands on. That is
> the only change of diameter anywhere in this conduit.
>
> It backs the bung across **95%** of its face. Without it the bung pushes
> against an open bore and most of the squeeze extrudes up the channel.
>
> **Bed the spigot properly on 4200 — that bond is the load path, not the foam
> ring.** The ring is 293 mm² at **2.17 MPa against H-80's 1.4**, so it would
> crush in on its own; the bond up the side of the spigot is 890 mm² in shear
> at **2.8×**. Skimp the bond and the ring is all that is left.
>
> **The slit is clearance, not a seal** — a slot rather than three holes,
> because the leads arrive in a row and a slot prints without bridging. The
> leads pull up through it at step 18 and only the bung grips them.

> **MACHINE THE MAST PLATE. Do not hand-drill it.** This guide used to say
> the Gong plate was jig enough — clamp, spot through, drill, tap. That
> reasoned from V1, where the holes were THROUGH holes with a nut on the far
> side and clearance quietly absorbed every error of position, angle and
> depth. **None of that is true here.** These are blind tapped holes: the
> thread *is* the fastener, and all four bolts must start at once.
>
> | | |
> |---|---|
> | Radial slop in Gong's clearance hole | 0.50 mm |
> | True position the pattern must hold | **0.25 mm** — errors at opposite corners add, they do not cancel |
> | Wander from a hole just 2° off | **0.35 mm** — more than the entire budget, on its own |
> | Solid alu left above the tap | **2.7 mm** before you breach the plate keeping the cavity dry |
>
> A hand-held drill is routinely 3–5° off. The arithmetic rules it out; this
> is not a matter of care.

**Position comes off the real mast, not off the drawing.** The 165 × 90 in
the CAD is unverified layout, and a perfectly machined plate on the wrong
pattern is still scrap. Clamp the mast to the blank and spot all four holes
with the **9 mm transfer punch** — it is a slip fit in Gong's own clearance
holes, so it marks true centre within a few hundredths. A 6.8 mm tap drill
rattling around inside that same 9 mm hole does not, and the whole positional
budget here is 0.25 mm. Then indicate off the four punch marks and machine to
them.

That splits the job the way it wants splitting: **the mast owns position, the
machine owns angle and depth**, and neither is asked to do the other's part.

**Route, in order of preference:**

1. **Job-shop it.** A 250 × 175 rectangle with four tapped holes is a trivial
   job, and cheap against the cost of getting it wrong.
2. **The makerspace CNC — if they permit aluminium.** It is a woodworking
   shop, so this is a question, not an assumption. Ask on the same call as
   the EPS one.
3. **Drill press**, with a bought drill bushing, a tapping guide and the
   depth stop set. Acceptable as a fallback. It is not the plan.

**Measure the real Gong plate first and machine to what you measured** — not
to the 165 × 90 nominal in the drawing, which is unverified layout only. A
perfectly machined plate on the wrong pattern is still scrap.

The bottoming tap still matters: blind at 10 mm in a 12.7 plate, and the
taper tap in the set cannot reach. Both plates nest on one 12 × 18 sheet.

Temper matters — this must say **T651**. 6061-O has about a fifth the yield,
and this plate carries 6.3 kN.

---

# Phase 2 — Laminate

Read [Appendix A](#appendix-a--vacuum-bagging-in-detail) before the first
session. The whole phase is governed by one number: **20 minutes of pot life.**

### Step 8. Set up the shop

**Blocks on:** —  *(do this while the printers run)*
**Uses:** `Folding sawhorses, pair, 700 lb` · `Pipe lagging or carpet, sawhorse padding` ·
`Rosin paper roll, floor and bench` · `Plastic sheeting + masking tape, bench protection` ·
`Thermometer / hygrometer, 2 pk` · `3M 60923 organic vapour / acid gas P100, pair` ·
`Nitrile gloves 6 mil, 100 pk`

Two padded sawhorses at ~30 in, rosin paper down. Cartridges expire — buy
them near the layup, not with the rest of the order.

### Step 9. Prove the vacuum rig before it matters

**Blocks on:** step 8
**Uses:** `VECOTOOLS 4.5 CFM single-stage pump, oil incl.` · `VR20 vacuum regulator` ·
`Vacuum gauge, -30 inHg, 1/4 NPT, glycerin` · `Bag connector w/ ball valve, 1/4 in QD` ·
`Vacuum hose + hose clamps` · `Vac bag film, 5 yd` · `Sealant tape, 50 ft roll`

Bag a scrap dry, pull down, **shut the ball valve** and watch the gauge for
30 minutes. That valve is why leak-down is a measurement and not a guess
about whether the pump is keeping up.

**Target 5–10 inHg, never more.** EPS crushes around 150 kPa and full vacuum
is 101 — the regulator is what stops the bag destroying the core.

### Step 10. Bottom skin

**Blocks on:** steps 7, 9
**Uses:** `E-glass 6 oz, 50in x 12ft, 2-pack` · `1708 biax, 50in x 10 yd roll` ·
`TotalBoat 5:1 gallon kit, slow hardener` · `Peel ply, 60in` ·
`Breather / bleeder cloth` · `Chip brushes 2 in, 36 pk` ·
`Laminating bubble roller kit, 4 pc`

**Both bottom layers in one session, always.** A second session onto cured
laminate is a secondary bond that needs sanding and washing first, and buys
nothing.

### Step 10a. Fit the rim ring — **before** you glass anything

**Blocks on:** steps 3, 7
**Uses:** `Acetone, solvent-welding the printed joints` ·
`Paste wax, releasing the groove filler` ·
`Black wax filler sticks, blocking + marking the bolt holes`

**The ring is glassed IN, not bonded on afterwards.** Acetone-weld the six
printed segments into one ring — a brushed acetone/ASA slurry makes it one
piece of plastic, not an adhesive line — then seat it on its ledge with the
printed filler strip **waxed** into the seal groove — and **press black wax
into all twelve bolt holes** before it goes down. That is not optional: resin
in a captive-nut pocket ruins it, and the black is what you line the template
up on at step 13. Keep the wax *inside* the holes and wipe the face.

It stays there through the cavity layup. The laminate runs up the cavity
wall, across the ledge and over the ring in one continuous piece, which is
the whole reason the groove is filled first: glass drapes over a 4 mm ridge
you can see and feel, instead of into a channel you then have to dig out.

**Dry-fit the caul now, with the ring in.** That is the only moment it is
free to discover the caul fouls something.

### Step 11. Deck skin and cavity

**Blocks on:** step 10 cured
**Uses:** `E-glass 6 oz, 50in x 12ft, 2-pack` · `1708 biax, 50in x 10 yd roll` ·
`TotalBoat 5:1 gallon kit, slow hardener` · `Peel ply, 60in` ·
`Breather / bleeder cloth` · `Release wax / PVA for the cavity caul`

The cavity is a **concave box** — a bag bridges it like a drum skin and
touches nothing inside. The caul does the work, not the bag: it is a male
plug (an EPS offcut, part 13) that drops onto the wet laminate so the bag
presses on *it*. Wax and PVA it properly; a caul bonded into a cured cavity
is not recoverable.

**The ring is in place for this**, so the caul is cut to fit around it: it
drops inside the ring's inner edge and stands the **full height from cavity
floor to ledge** — board thickness less the lid, the ring and the floor. Take
the number off part 13 in [cut-list.md](../cnc/cut-list.md) rather than from
here; it moves whenever the lid stack or the ring does, and this paragraph
used to carry a hard 100.1 that was two geometries out of date.

That height is the point. The caul was once specified at the *module's*
height, which is a different measurement and several millimetres short. It
stopped below the ledge, so the wall-to-ledge corner — concave, exactly where
a bag bridges — got pressure from neither caul nor bag. That corner is where
the ring sits and where the seal ends up.

### Step 11a. Lay up the two lids

**Blocks on:** step 9
**Uses:** `Divinycell H-100 1/4in quarter 21x42, hatch lid cores - 2 sheets bonded to 1/2in` ·
`Divinycell H-80 1/4in quarter 24x48, module lid cores` ·
`E-glass 6 oz, 50in x 12ft, 2-pack` · `TotalBoat 5:1 gallon kit, slow hardener` ·
`Peel ply, 60in` · `Breather / bleeder cloth` ·
`1/4 in composite bit - lid profiles` · `Carbide-tipped drills 5.0 + 5.6 mm, the lid bolt holes` ·
`Ryobi ONE+ P601 trim router, tool only` ·
`Compression flush-trim bit, 1/4 in shank, lid masters`

Both lids are flat sandwiches — glass / foam / glass — so they bag on the
bench and **do not need the board**. Do them alongside a hull session while
the pump is already set up and mixed resin is going spare.

The hatch lid core is **H-100**, and it is two ¼ in sheets bonded to ½ in
because no ½ in H-100 is made. That grade is deliberate: you stand on this
one. The module lid is H-80 — nobody stands on it.

**Both cores get their epoxy plugs first — hatch and module alike.** The
hatch lid's are written up in detail under
[step 13](#the-plugs-are-cast-into-the-bare-core-before-the-skins-go-on)
(the operation belongs here, at layup — that write-up sits later in the
document than the step that performs it) and the
module lid's are the same operation at a smaller size: **18 × Ø12 through the
bare H-80 sheet, tape one face, pour thickened epoxy, cure, sand both faces
flush**, then lay up over it. The module lid used to say *drill Ø12 through
the top skin and core only, leave the bottom skin* — that is a
**depth-controlled cut into a bagged laminate**, whose thickness is whatever
the bag gave you that day, and 0.5 mm too deep opens the face that seals the
module. Same trap the hatch lid was pulled out of; it just took longer to
find here.

**Both cores are cut OVERSIZE — 6 mm all round — not inset.** Parts 03 and 11
are bigger than the lids they go inside. The profile is machined through
glass / core / glass in one pass after cure, so there is no skin wrapping the
edge to preserve; [step 12](#step-12-seal-every-cut-edge)'s neat epoxy is
what protects the exposed core. Cutting the core inset *and* machining to
profile were mutually exclusive and the drawings asked for both.

#### Trimming them needs a machine, a bit, and a second visit

Trim to net profile after cure (parts 02 and 10 — their cores 03 and 11 are
inside the sandwich by now), and face the hatch lid's underside flat in the
same setup: it has to bottom evenly on the seal land.

**This is the one operation in the build that cuts cured glass**, and none of
the cutters bought for the core will do it. Foam bits are ground for foam;
glass does not blunt a bit so much as sand it round, and there are **6.6 m of
laminated edge** here across two boards. Two composite bits are on the list:

| | |
|---|---|
| Profiles | **¼ in Amana 46094** — 19 mm of cutting height on a 15.2 mm lid |
| All 29 holes a board | **⅛ in Amana 46091**, and *the ⅛ in shank is the spec* |

Ø5.0 and Ø5.6 are smaller than the profile bit, so they cannot be
circle-milled with it. A ⅛ in cutter on a ¼ in shank is no good either — the
shank stops on the hole at 12.7 mm and the hatch lid is 15.2 thick. A ⅛ in
shank is 3.175 and goes straight down a Ø5.0. **Check the shop has a ⅛ in
collet before the day** — it is a $15 part and a wasted trip.

**CNC both lids — profile and holes, one setup each.** That is the better
answer and the pigment is what makes it possible: register the panel by
touching off on **two visible plugs**, which gives the machine an origin and
a rotation, and everything it cuts afterwards is referenced to the plugs
rather than to the blank edge. Core drift stops existing as a tolerance, and
the machine holds the rest of the pattern far better than a hand-guided bit.

> **This has to land inside the CNC month, which is a scheduling
> requirement and not an obvious one.** The order is: cut the cores on the
> first visit → pour and cure the plugs → **get the vacuum rig up (steps 8–9)
> and lay the lids up** → come back for a second visit. The Basic month gives
> 8 visits in 30 days, so two is easy; what is *not* easy is having the bag
> and pump working three weeks earlier than the build order otherwise needs
> them. Plan for it, or budget a **$99 day pass** for a later visit.
>
> **And it is the fibreglass half of the phone call.** Machining the lids
> means running cured glass laminate on their router — same conversation as
> the EPS question, and it should happen in the same call.

**The MDF masters are cut anyway, and stay as the fallback.** They come off
the same first CNC visit in wood, which nobody objects to. If the shop turns
out not to allow glass, or the calendar slips past the month, the holes get
drilled in the bare core off the masters and the profile flush-trimmed at
home with the P601 — see the note on parts 16 and 17.

> **Rough-cut before you trim.** A flush bit takes the last millimetre or two
> off, not the 6 mm the cores are bagged oversize by. Jigsaw or bandsaw close
> to the master first.
>
> **The rotary tool will not do this one.** It is right for the seal groove —
> 0.6 mm of glass off a filler strip, which wants control, not power. This is
> **6.9 m** of glass/foam sandwich edge across both boards and the hatch lid
> is **15.2 mm** thick: a ¼ in collet and real torque. The compression
> geometry matters too — up-cut at the tip, down-cut above, so both skins get
> pulled *into* the laminate and neither splinters at the edge.

### Step 12. Seal every cut edge

**Blocks on:** step 11
**Uses:** `TotalBoat 5:1 quart kit, fillets and bonding`

Neat epoxy into groove walls, the lid perimeter, all 12 lid bores, every
machined edge. **This is V1's leak, verbatim** — its own notes read *"cured
laminate is NOT waterproof at a cut edge."* Water came in through unsealed
fibre ends at the cavity ledge.

---

# Phase 3 — Hatch and module

### Step 13. Open the groove and bond the cord in

**Blocks on:** steps 10a, 11
**Uses:** `Acetone, solvent-welding the printed joints` ·
`Paste wax, releasing the groove filler` ·
`Solid silicone cord, 3 mm round - BOTH seals` ·
`Silicone adhesive, bonding the cord into groove` ·
`2.5 mm straight cutter, opening the seal groove` ·
`1/4 to 1/8 in collet reducer, for the 2.5 mm groove cutter` ·
`M5 x 25 button head TORX TX25, 25 pk` · `Transfer screw set M3-M6` ·
`Solid silicone cord, 1/8 in (3.175 mm) - the spare size`

The ring went in at step 10a and has been glassed over since — **the whole
face, under 0.6 mm of laminate, bolt holes included.** Two different jobs
to open it again, and they are deliberately not the same job.

**The groove is ROUTED, off template 14.** The filler strip prints **flush**,
so the laminate over the seal land is flat — no step for the glass to bridge
at. Locate the template on the **rebate wall**: 34 mm of CNC ledge with a
vertical wall running the whole perimeter, true by construction and
continuous round the corners where a straight fence could not follow. A
**2.5 mm cutter in the 4 mm groove** leaves **0.75 mm** of lateral slop each
side before it can reach the land. Set the depth to just break into the
filler — you will feel it go soft — then pick the filler out and the
**printed walls are the finished groove**.

> **Why flush and not proud.** An earlier scheme printed the filler 0.5 mm
> proud so the glass draped over a ridge you could sand down to. Self-finding
> and no template — but it ran a 0.5 mm step **1.8 m along the sealing land**,
> and glass bridges at the two inside corners of a step. That seeds a pair of
> void-prone lines either side of the groove, in the one band of laminate the
> cord has to land on, and sanding back to the ring face lands about *at*
> those corners rather than safely past them.

**The twelve bolt holes are found with the same template, backed up by
coloured wax.** The holes have to be blocked during layup regardless — resin
in a nut pocket ruins it — so the wax that blocks them also marks them: it
reads through the thin laminate afterwards, well enough to line the template
up on. Align it on the two or three that show clearly and the rest are right
by construction, then drill through the bushings.

> **Template and lid come off one master.** The 12 circles in part 14 are the
> same bolt ring that cuts `02_hatch_lid`, and the same one that places the
> ring's captive nuts. There is no second set of numbers anywhere to
> disagree — the guide, the lid and the nuts are one pattern expressed three
> times.
>
> The two halves cover each other. The **template is exact** but references
> the rebate, so it carries whatever the ring drifted when it was seated. The
> **wax marks are on the ring** and cannot drift, but are only semi-visible.
> Neither alone is enough; together they are.

> **Nothing is printed on this face — not proud, not recessed.** Raised pips
> were the obvious way to find the holes and they fail twice. One surviving to
> assembly holds the lid **0.5 mm off the ring face**: the cord stands only
> 0.6 proud of its groove, so squeeze goes 20% → **3%**, under the 10% floor,
> and the seal is dead. And even sanded away, the glass that bridged around it
> leaves a **void at r = 3–5 mm** — inside the Ø18 washer, in the crush path.
> Recessed dimples fix both, but a dimple is still a feature cut into the one
> face whose whole job is to be flat and continuous.
>
> **Keep the wax inside the hole and wipe the face before layup.** Wax on the
> sealing land is a release agent in a bond line, under the washer — the same
> mistake as the pip, arriving a different way.

**Wet the opened groove with neat epoxy before the cord goes in.** Sanding or
routing leaves cut glass ends in the seal itself, which is the same wick that
flooded V1. Silicone adhesive does not stop a wick; epoxy does.

Bond the cord in on a thin continuous bead. Splice on a straight run, never a
corner.

> **Replacing it later is destructive, and worth knowing now.** A bonded
> cord comes out by cutting it, then cleaning the groove back to bare walls
> with a plastic scraper and acetone — RTV will not bond to old RTV. Keep the
> spare cord and the silicone adhesive with the board. On a joint opened every
> ride, the day the cord needs replacing is not a day you want to be
> discovering how.

**Measure the finished groove before choosing cord.** Nominal is 2.4 mm deep,
which the 3 mm cord squeezes 20%. If it routs deep the 3 mm only reaches 10%
and you want the 1/8 in spare instead — that is what it is for. Guessing the
cord before the groove exists is how you end up at 10%.

**The twelve heads sit proud, and there is nothing under them but a plug.**
The bolt ring is in the only bare band on the whole deck — the deck pad stops
20 mm outboard of the rim, the lid's own pad sits inboard — so it is the most
visible hardware on the board. It is also the most loaded.

**The load under the head is the PRELOAD, not what the seal needs.** The cord
only wants **182 N** a bolt. At the 1.2 Nm spec each bolt actually delivers
**1200 N**, and the surplus does not evaporate — it goes into the lid under
the head, on 32 mm².

The 1 mm skin does not pass that straight down; it carries it sideways into
the core for about **16 mm past the edge** of whatever presses on it — the
same beam-on-elastic-foundation model the heel check uses. Even crediting
that:

| Seat | Pressure | vs H100's 2.0 MPa |
|---|---|---|
| Bare M5 **button** head, Ø9.5 | 1.92 MPa | passes, 1.04× — the bolt actually specced, and it is *this* close |
| Bare M5 socket cap, Ø8.5 | 2.06 MPa | **fails, 0.97×** — a narrower head is worse, and a cap head is what an earlier draft had |
| Ø18 penny washer | 1.12 MPa | passes, 1.79× |
| **On the epoxy plug, Ø18 washer** | **6.8 MPa vs epoxy's ~50** | **7.4×, and the foam carries none** |

> **Why the lid needs a hardpoint at all.** It is glass / H100 foam / glass,
> and a bolt clamped straight onto that crushes the foam. So at every bolt the
> core is replaced by a plug of solid resin, and the lid reads glass / **solid
> epoxy** / glass instead of glass / foam / glass. Same trick every deck
> fitting on a boat or a surfboard uses. V1 never needed it: that lid was
> solid plywood all the way through.

#### The plugs are cast into the bare core, before the skins go on

That timing is the whole trick. The core is a flat sheet on the bench with
nothing laminated to it yet, so making twelve hardpoints is **pour, cure,
sand** — no pocket milled to depth in a finished panel, no bolt hole filled in
and re-drilled, and nothing to hunt for under a cured skin afterwards.

1. **CNC the core** oversize, with twelve Ø16 through-holes.
2. **Tape one face, fill them with thickened epoxy — pigmented BLACK** —
   cure, and **sand both faces flush.** A plug left proud prints through a
   1 mm skin under vacuum and you get twelve bumps in the deck.
3. **Lay up** glass / core / glass and bag it. The plugs are invisible now —
   except that they are black, and read through a 1 mm skin.
4. **CNC the profile only, registered on two of the plugs.** Touch off on one
   plug for the origin and a second for rotation. No holes on the machine.
5. **Drop master 17 onto the finished profile, clamp, and drill the twelve
   Ø5.6 through its bushings.** The master *is* the profile, so it
   self-locates — and because the profile was cut off the plugs, its holes
   are already over them.

> **The chain closes on itself, which is the point.** The profile is
> registered to the plugs; the master is registered to the profile;
> therefore the holes are registered to the plugs — without anyone having to
> aim at something they cannot see. The machine does the job it is better at
> and you do the thirty holes through a bushing, which a second CNC setup
> with tiny bits in abrasive glass buys nothing over.
>
> **Without the pigment there is nothing to touch off on** — the machine
> would cut a perfect profile in the wrong place, and the first sign would be
> a bolt breaking out the side of its plug.
>
> **Mark which way round the master goes.** A rounded rectangle drops onto
> its own profile equally well at 180°, and the bolt pattern will not tell
> you. One witness mark on the master and one on the lid, made before the
> master ever leaves the sheet.
>
> **Back the exit face with scrap.** Carbide-tipped drills, not HSS — glass
> does not blunt a drill so much as sand it round, and there are 58 holes
> across both boards.

Twelve holes bored in one setup are mutually accurate to the machine, so
lining the lid up on the ring is a single **rigid-body fit**: get two to pick
up and the rest already are.

**The core can drift 4.2 mm at layup** and the bolt still lands inside its
plug with resin all round it. That is what buys you the freedom to place the
core by hand.

**A Ø18 penny washer goes under each head, and it is not decoration.** A bare
M5 button head on resin is 37 MPa — 75% of ultimate — and epoxy cold-flows under
permanent preload. On the washer it is 6.8, or 14%. Same washer as the one
captive under the nut, so it is one size in the drawer and two per bolt.

**Button heads, proud, on washers — no countersink.** The head is domed and
2.75 tall against a cap head's square-edged 5.0, and the whole stack finishes
1.5 mm *below* the deck pad beside it. This is a band you walk on barefoot.

**Torx, and this is the only joint on the board that gets it.** The hatch is
the one thing opened *every ride*, in sand. A packed hex socket lets the key
bottom early and the head rounds — and a rounded head here means drilling a
bolt out of a lid you cannot easily replace. Torx tolerates a partly-seated
driver, which is exactly that failure.

The module lid (M4, inside the cavity, opened twice a year), the rail handles
(fitted once) and the drivetrain all stay hex — each would only add a driver
size for nothing. **Keep both Torx keys with the board: T30 is Gong's, for the
mast. T25 is the hatch.**

**If one hole still will not pick up**, that is what the transfer screws are
for: mark the real nut, open that hole, and leave the other eleven alone. The
plug is 5.2 mm bigger than the bolt all round, so there is room to move it.

**Seal the bores** with neat epoxy as [step 12](#step-12-seal-every-cut-edge)
did for the rest — the drill cuts both skins, and those are fresh fibre ends.

### Step 14. Build the module

**Blocks on:** step 3
**Uses:** `5052 1/8in x 12 x 24, 2-pack - module floors` ·
`Sikaflex-292 marine structural PU` · `Sika Aktivator-PRO 250 ml + daubers` ·
`2 mm glass beads or shim wire, bond-line control` ·
`M4 x 12.7 LONG brass heat-set insert, 50 pc` · `M6 x 12.7 brass heat-set insert, 50 pc` ·
`Closed-cell sponge EPDM 1/8in, module lid gasket` · `Hollow punch set 1/8-1/2in + cutting mat` ·
`Gebildet PG11 gland, M18x1.5, 30 pk` · `GORE PolyVent Stainless M12x1.5, module vent` ·
`M12 IP68 momentary panel button` · `JST GH 1.25 mm pigtail pair, BMS switch` · `SP17 2-pin IP68 flange socket + mating plug` ·
`M3 heat-set insert kit, 361 pc` · `M3 x 8 A4 stainless, 10 pk`

> **The 18 lid inserts, and the torque that goes with them.** Derek pulled a
> heat-set out of V1 while fixing it, so this is a measured failure, not a
> margin exercise — and the fix is two things, of which the insert is the
> smaller.
>
> **Longer, not fatter.** Pull-out goes as π × D × L, but *diameter also has
> to fit the flange land* and length doesn't — it just goes down into rail
> that was doing nothing:
>
> | Insert | Pull-out | |
> |---|---|---|
> | M4 × 8 (V1's) | 800 N | |
> | M5 × 9.5 | 1086 N | starts crowding the land |
> | M6 × 12.7 | 1860 N | **fails two land checks** — 2.4 mm of ASA left outboard, gasket band running into the bore |
> | **M4 × 12.7** | **1270 N** | same bolt, same Ø5.6 pilot, same gasket punch, same board thickness |
>
> The flange rail goes 9.5 → 14.5 mm deep to swallow it, with 1.8 mm of
> backing under. That costs nothing: the rail hangs on the *outside* of the
> wall, so it grows down into a gap that was already there.
>
> **And the torque matters more than the insert does.** This lid has never had
> a spec, and an M4 is unforgiving about it:
>
> | | Preload | On the insert |
> |---|---|---|
> | 0.5 Nm | 625 N | **2.0×** |
> | 1.0 Nm | 1250 N | 1.0× — at its limit |
> | 2.0 Nm | 2500 N | 0.5× — **this is how you pull one out** |
>
> 2 Nm is barely a wrist on an M4. **Spec is 0.5 Nm**, which is below any
> torque wrench, so it is a feel spec: shortest key you own, two fingers, stop
> as soon as it stops turning easily. That is still **4.1× what the seal
> actually needs** — the squeeze is geometric, the lid lands on the flange,
> and there is nothing to gain past that point and an insert to lose.

Acetone-weld the four printed L-pieces into a shell. Bond it to the 5052
floor on a **2 mm controlled bond line** — glass beads set the gap, fillet
both sides. It must be flexible PU, not epoxy: ASA and aluminium differ by
66 µm/m·K, which is 0.60 mm of movement from the centre over 40 °C. A rigid
line sees 299% shear strain and tears itself apart.

Heat-set the lid inserts into the printed flange. The M3 kit's screws are
plain steel — use the A4 ones for the port flange, which lives in the wet.

**Four M5 inserts go in at the same time**, two into each lift-handle pad on
the aft wall, 18 mm apart. Do them while the shell is on the bench and open —
they are 8 mm-proud pads on the outside of a box you are about to seal, and
the soldering iron wants room.

### Step 15. Leak-test the module empty

**Blocks on:** step 14
**Uses:** `Test cap + tubing, module leak test` ·
`Bag connector w/ ball valve, 1/4 in QD` · `Gebildet PG11 gland, M18x1.5, 30 pk`

**The module has no test port — and does not need one. A gland is a test
port.** At this stage no cables are fitted and all three PG11 glands are
empty. A gland is a compression seal on a round thing, so feed one of the
test kit's smaller hoses through it and tighten. Blank the other two glands
and the vent boss. No extra hole, no special fitting.

*(The first plan here was an M12 × 0.75 barb into the vent boss. That is a
fine pitch nobody stocks — and it was the wrong problem: the sealing hardware
you already have does the job.)*

**The vent must be OUT while you test.** An ePTFE membrane passes air by
design — that is the entire point of it — so with the vent fitted the module
cannot hold vacuum and there is nothing to measure. That is not the vent
defeating the design, it is the vent defeating the *test*, which is why the
test comes first and the vent goes in after. The two jobs are different:

- the **seals** stop liquid water
- the **vent** passes air, so the module breathes through a filtered path
  instead of pumping through a marginal gasket every time it goes from cold
  water to hot sun

**Vacuum, not pressure.** Submerged, the module sees external pressure
pushing the lid *onto* its gasket — vacuum inside reproduces that direction.
Pressure inside tests the opposite and would fail a joint the board never
loads that way. It is also unsafe: 0.2 bar across a 443 × 314 lid is about
**2.8 kN**.

**Prove it before the cells go in.** Seal it empty, pull 5 inHg, shut the
ball valve, watch the gauge 30 minutes — porosity reads as a slow bleed. Then
do it **submerged**: under vacuum any path pulls water *in* and shows you
exactly where. V1 found its leaks by riding.

---

# Phase 4 — Pack and electronics

Runs entirely in parallel with Phases 1–3.

### Step 16. Build the pack

**Blocks on:** step 1
**Uses:** `BAK N21700CG-50, 130-cell case (BatteryHookup)` ·
`BAK N21700CG-50 singles, spares` · `Pure nickel 0.2 x 10 mm, 5 m roll` ·
`Kapton tape, pack insulation` · `PVC pack wrap, 200 mm lay-flat` ·
`DALY Smart BMS Li-ion 16S 60V 150A` · `Silicone sealant, BMS anti-vibration dabs`

16S8P, 128 cells, 2,304 Wh, 9.22 kg. Confirm the BMS is **Li-ion, not
LiFePO4** — different chemistry and pack voltage, and it is the easy wrong
answer at a glance. Silicone dabs stop the BMS walking; V1 needed them.

### Step 17. Wire the module

**The VX3 receiver goes wherever it is out of the way.** V1 ran it inside an
enclosure with a bolted *aluminium* lid, under a plywood hatch, and it worked
— so V2's ASA walls and glass/foam lids are no obstacle at all. It is tiny.
Tuck it clear of the wiring and forget about it.

**Blocks on:** steps 15, 16
**Uses:** `8 AWG silicone, 10 ft red + 10 ft black` · `16 AWG silicone, 6 colours x 5 ft` ·
`ANL 150 A fuse + holder` · `Inline 10 A fuse + holder, charge lead` ·
`8 AWG marine ring lugs, 20 pk` ·
`Hydraulic lug crimper, 10 ton, 12-2/0 AWG` ·
`Adhesive-lined heat shrink 3:1, 400 pc kit` · `5.5 mm gold bullets, 20 pair` ·
`Dielectric grease, terminals` ·
`Cable ties, lacing, adhesive mounts` · `Thermal pad 1 mm non-conductive, 100 x 100` ·
`Silica gel, indicating, 50 g per module` · `Water-ingress alarm, 2 pk`

Crimped, not soldered. The thermal pad **must be non-conductive** — the ESC
PCB face goes down onto an aluminium floor and a metal-loaded pad is a dead
short. Put the leak alarm's sensor on the module floor in the lowest corner,
not up on the pack.

**The full topology, every joint and every crimp, is
[Appendix D](#appendix-d--wiring).** Read it before you cut a single lead —
it answers where P+ splits, what the fuse protects, and the two mistakes
that kill a BMS.

### Step 18. Run the mast conduit and fit the wire bung

**Blocks on:** steps 7, 17
**Uses:** `Fish tape / pull cord for the mast conduit` ·
`IP68 M25 inline housing, 5 pk` · `Neoprene sheet 1/2in, wire bung` ·
`Hollow punch set 3/16-1-3/8in, for the O30 bung` ·
`3M 4200 FC 3 oz tube, skim over the bung`

Motor leads part **in the cavity**, one housing per phase — without that the
mast is bolted on for life.

> **The conduit is two straight bores, and you drill the second one.** One
> goes **straight up** from the mast plate, 32 mm of it. The other is drilled
> **down from inside the cavity at 48°**, 43 mm of it, and they meet in the
> foam at z=30 — **3.8 mm above the blocker's spigot**, so it does not break
> into it.
>
> An earlier version of this drawing had a swept curve through the foam. That
> was not a buildable part: this channel is cut **by hand at step 18**, into a
> board that has been assembled since step 7, and no drill makes a radius
> through a bonded-in block from either end.
>
> **The lead does not need a bend radius — it cuts the corner.** The bores are
> Ø22 and the lead is 6.5, so it can arc through the junction at an effective
> **116 mm radius, 4.5× what 8 AWG wants**. Ease the corner with a round file
> anyway before you pull.

**The bung's first job is not sealing, it is spacing.** The three phase leads
come out of the mast *touching*, in a line along the chord — an alu mast's
internal cavity is only about 12–14 mm across, so 6.5 mm leads cannot lie any
other way in there. Three touching jackets are three capillary paths: sealant
bridges the gaps between them instead of going round each lead. The bung
holds them **in that same line** with 1.5 mm of rubber between every pair,
and *that* is what makes the seal possible.

A triangle would pack smaller, and the bore was originally shrunk around one.
But it asks all three leads to twist through 90° in the few millimetres
between the mast top and the bung, by hand, upside down, in 8 AWG silicone.
Matching how they arrive is worth more than the packing.

**What the row used to cost, and no longer does:** a row is wider than the
round bore it feeds, so the outer lead has always had to converge slightly on
its way up. At a 2.0 mm wire gap it left the bung 11.75 mm off the axis
against a bore that allows **11.0 mm** and had to bend into a 24 mm effective
radius — under the 26 mm this cable wants. At 1.5 it was 11.25 and a 72 mm
radius, 2.8×, fine.

At the **7.5 mm pitch** the gap is 1.0 and the outer lead leaves the bung
**10.75 mm** off the axis — *inside* the bore before it gets there. **It does
not converge at all.** The failure mode is not smaller, it is gone, and that
is what the half millimetre bought.

**Where the compression comes from.** There are **two aluminium plates** at
this joint. The board's hardpoint is bonded into the hull bottom at step 7 and
never moves again. **The Gong mast has its own plate**, with four *clearance*
holes, and its bolts pass up through them into the tapped hardpoint — so that
plate is the part that travels, and tightening draws it face to face with the
bottom of the board. Anything standing proud of that face gets squeezed, with
four M6s behind it. That is the only travel in the whole mast joint.

1. Punch Ø30.0 discs from the 3/4 in sheet and drill 3 × **Ø5.5 in a row at
   7.5 pitch**, along the chord — the order the leads leave the mast in, so
   not one of them has to be twisted. The holes are drilled **undersize on
   purpose**: 5.5 into a 6.5 lead is the 15.4% interference that *is* the
   seal.
2. Thread the leads through on the bench and soap them.
3. Feed the bung up the plate's straight **Ø30.8 bore**. It butts the epoxy
   liner's end face where the foam channel steps down, and hangs **4.0 mm
   proud** of the wetted face.
4. Bolt the mast on. Its plate squeezes that 4.0 mm out, and the rubber —
   with nowhere useful to go — closes onto the jackets and the bore wall.
   **Start all four bolts by hand before torquing any of them**, or the plate
   rocks on the bung. 159 N a bolt to close it.

| | |
|---|---|
| Disc | **Ø30.0 × 12.7**, punched from 1/2 in neoprene |
| Holes | 3 × **Ø5.5** in a row at 7.5 pitch — **15.4%** under the lead |
| Bore | the plate's own **Ø30.8**, one straight pass, no step |
| Rubber wall | **4.25 mm at the ends of the row**, 11.75 at the sides |
| Backed above | **95%**, by the blocker |
| Proud | **4.0 mm** below the wetted face |
| Grip on the leads | **8.7 mm** at 15.4% interference |

> **Why it is round and not a rectangle.** A row of holes inside a circle is
> fat where it needn't be and thin exactly where the outer two leads sit — at
> Ø26 that was 9.75 mm of rubber at the sides and **1.75 at the ends**. A
> rectangular bore would even that out. It would also be **milled instead of
> drilled and reamed**, and that bore's *finish is the seal*, with corners for
> leak paths. Growing the circle to Ø30 fixes the same problem for 4 mm of
> hole in a plate with 63 mm of clearance to its nearest bolt.

> **What seals here, in order.** Three mechanical barriers in series, and no
> sealant is load-bearing:
>
> 1. **The Ø5.5 holes at 15.4% on the leads.** A grommet seal — it does not
>    need the squeeze at all, which is why they are drilled that tight.
> 2. **The bung's OD closing onto the plate's bore**, driven by the squeeze
>    the blocker now makes possible: **95% backed** instead of 30%.
> 3. **The blocker bedded on 4200** into the foam counterbore, which seals the
>    annulus round it — an adhesive use, not a wire seal.
>
> Nothing in the *channel* is a sealant barrier. That was the
> point of the blocker: an earlier version had the bung butting an epoxy liner
> step that **has no geometry** — the dense block is bored clean through — and
> had it existed it would have been a 365 mm² ring carrying 1.72 MPa into H-80
> that gives up at 1.4. The stop was imaginary and undersized at once.

> **The bung has to be wider than the mast's wire slot**, or the plate has
> nothing to push on. Derek's slot is **20.4 × 7**, cut just wide enough for
> the three leads, and it sits wholly under the bung — so it costs only its
> own 143 mm² and the plate keeps **89% of the bung's face**. No follower, no
> flange, no spotface.
>
> **Open the slot to 22.5 mm** while you are at it. The leads reach the bung's
> holes at 7.5 pitch, which puts the outer two 10.75 mm off the axis against a
> slot that reaches 10.2 — they would bear on its ends. Not a leak path, but a
> chafe point on something that vibrates. It costs 2 points of land.

It also holds itself in at about **253 N** of friction against the **37 N** a 5 m
water column pushes up under it — 6.8×. It comes out the way it went in: cut the fillet,
pull the leads and the bung down together.

Fillet 4200 over the underside. **4200 not 5200** — 5200 never comes out.

> **Why the pocket is 2.25 mm bigger than the disc.** Rubber does not
> compress, it *moves*. A bung squeezed in a bore it exactly fills cannot be
> squeezed at all — it becomes a solid spacer and the four M6s fight it for
> nothing. The clearance annulus is the only place the displaced rubber can
> go, so it is relief, not slop, and it is sized to swallow the 1 mm squeeze
> *plus* a hand-punched disc coming out a millimetre over.

---

# Phase 5 — Finishing

### Step 19. Fair

**Blocks on:** step 12
**Uses:** `TotalBoat TotalFair epoxy fairing compound` ·
`Flex longboard sander, 16-1/2 x 2-3/4` · `Adjustable hand sanding block` ·
`Longboard PSA sandpaper 80 grit, 20 yd roll` ·
`Longboard PSA sandpaper 120-180 grit, 20 yd roll`

**Flex longboard, not a rigid block.** The deck is crowned and the bottom
rockered; a rigid block bridges the curve and cuts flats you then have to
fair back out. 80 grit cuts fair, it does not finish.

### Step 20. Prime and paint

**Blocks on:** step 19
**Uses:** `TotalBoat Premium Marine Topside Primer` ·
`TotalBoat Wet Edge topside paint, colour` · `Wet/dry sandpaper assortment, 45 pc`

Wash before any secondary bond — amine blush comes off with **water**, not
solvent. Acetone smears it around.

### Step 21. Deck pad

**Blocks on:** step 20
**Uses:** `FOCEAN EVA deck sheet 2400 x 600 x 5.8`

Three pieces per board — aft of the hatch, forward of it, and one on the lid.
One sheet does both boards. Pattern is part 15 in
[cut-list.md](../cnc/cut-list.md).

Cut **long** and trim on the board; with no seams the crown's arc excess goes
into stretch and the trim at the rail. Peel the backing progressively from
the centreline outward — a 5.8 mm sheet laid in one go traps air it will not
give back.

---

# Phase 6 — Assembly and first water

### Step 22. Fit out

**Blocks on:** steps 18, 21
**Uses:** `Kayak/board grab handle, 2 pk + screws` · `M6 x 16 A4 button head, 10 pk` ·
`M6 x 16 A4 button head, 10 pk` ·
`Leash plug 30 x 12.5, stainless pin, 2 pk` · `Coiled ankle leash` ·
`M4 x 12 A4 socket cap DIN912, 10 pk` · `M4 A4 washer, 316, 100 pk`

**Three handles a board, all the same part:** two on the rails into the 6061
strip, one on the electronics module. Drill the handle's reinforcing holes to
suit rather than using the supplied screws anywhere: **M6** into the tapped
6061 on the rails, **M5** into the module's heat-set pads. The supplied screws
are self-tappers, and a self-tapper in a brass insert is a stripped insert.

**Measure the handle's tabs before you drill the module one.** The rail pair
is on 152.6 mm centres and has room either side; the module's pads are on 70 mm
and cannot move — outboard of them is 5 mm of clearance to the gland nuts. If
the bought handle's tabs are much wider than 70 mm, put a webbing loop through
the same two pads on the module and keep the bought handles for the rails.

> **Still open: what holds the module down in the cavity?** Its 18 bolts hold
> its own lid on, not the module into the board. A 14 kg module loose in a
> cavity is the heaviest thing aboard with nothing restraining it. **Decide
> before the cavity is glassed** — anything bonded in has to go in before the
> laminate does.

### Step 23. Mount the foil and drivetrain

**Blocks on:** steps 7, 22
**Torque the four mast screws to 5.3 Nm (47 in-lb), Tef-Gel on every
thread — and re-torque every time the mast goes back on.** There was no spec
for this joint at all; every other bolt on the board had one. It is derived
(~65% of the M6 A4-70's proof load through K = 0.15, *lubricated*), and it
sits at the top of the 10–50 in-lb wrench already on the list. Do not use a
dry-thread figure — it over-tensions a greased bolt by about a third.

**Uses:** `M6 x 22 A4 countersunk DIN7991, mast screws` · `Ultra Tef-Gel, galvanic barrier` ·
`M5 x 250 threaded rod, 4 pk (cut to ~171 mm)` · `M6 x 20 fender washer, 100 pk` ·
`M5 nyloc nut 316, 150 pk` · `Loctite 242` · `Roll pin assortment M1.5-M6, 220 pc` ·
`M8 nyloc nut 316, 30 pk - prop nut` · `M8 316 washer, prop nut` ·
`1/4 in torque wrench, 10-50 in-lb`

**Tef-Gel every mast bolt, every time.** Aluminium plate, A4 bolts, wet
cavity — that is the whole galvanic mitigation and it is not optional.

> **The mast screws are M6, and Gong supplies them.** The setup ships with
> *7 × M6×30 mast screws, 4 M6 brass square nuts, 4 M6 cup washers and a T30
> Torx key.* The square nuts are for a US-rail board and you will not use
> them; the cup washers and the screws you will. **T30 Torx, not hex** — the
> spares line is hex-drive A4, so keep Gong's key with the board.
>
> This model said M8 until it was checked against Gong's own contents list.
> The correction costs real margin — **the joint is 1.44× on the roll case,
> not 2.63×** — but not margin anyone here can buy back, and that is the
> point. M6 A4-70 proofs at 9.0 kN against the 6.3 kN that case demands.
>
> **The screw is the weak link, and it is Gong's.** Our side of the joint is
> 10 mm of tapped 6061 in a 12.7 plate at **13.2 kN — 46% stronger than the
> screw going through it.** Their own system reacts that same screw into a
> brass square nut floating in a US box, which is weaker than this. So V2's
> mast joint is stronger than the boards Gong designed the fitting for, and
> tapping deeper or fatter buys nothing.
>
> The 1.44× is also against **proof** load — the point permanent set begins —
> not ultimate. Against actual failure it is around 2.0×.

**No gasket goes under the mast base**, and there is none in the BOM.

**V1 had one, and it was doing a job V2 does somewhere else.** On V1 that
gasket was the waterproofing for the mast penetration. V2 seals the hole the
wires actually run up instead — the Ø26 conduit gets a punched EPDM bung and
a 4200 fillet in
[step 18](#step-18-run-the-mast-conduit-and-fit-the-wire-bung) — so the
barrier sits at the bore, not under the plate. Sealing both would be sealing
it twice.

Which leaves nothing for a gasket here to do: the mast bolt holes are
**blind**, so there is no path into the board through them, and the faying
faces are aluminium on aluminium — the galvanic couple is the A4 bolts.
Smear Tef-Gel across the mating faces as well as the threads and pull the
plate down metal to metal.

And a gasket would cost something real. This is the highest-loaded joint on
the board — an 850 mm lever with rider weight and foil lift at the end.
Rubber under 4 × M6 creeps, the bolts lose preload, and the plate starts to
rock. Compressible is the wrong property here in either material.

**Measure** the prop shaft cross-hole rather than trusting the 4 mm figure;
that is why the roll pin line is an assortment.

The torque wrench is a **calibration tool**: set the drill clutch with it,
then use the clutch. Hatch spec is 1.2 Nm — 10.6 in-lb, which is *below* the
floor of the common 20–200 in-lb wrenches, hence the 10–50 one.

### Step 24. Seal, charge, and go

**Blocks on:** step 23
**Uses:** `Silicone grease for the seal cord` · `Charger 67.2 V 5 A, 16S  (NOT 58.8 V)`

Grease the cord so it does not bond to the lid in storage. Confirm the
charger is **67.2 V** — a 58.8 V charger is a 14S charger and will never fill
this pack.

First session: bag-test the module one more time, then ride it shallow.

---

# Appendix A — Vacuum bagging in detail

### The number that shapes everything: 20 minutes

Slow hardener is 20 minutes of pot life at 75 °F. That is the entire design
constraint on every session — how much you can mix, how much you can wet out,
how far you can be from the bag when it starts to go off.

Mix in **small batches**, never one big pot. A full pot goes off in the pot.

### Building through a Boise winter

| Hardener | Minimum | Pot life |
|---|---|---|
| Slow | 60 °F | 20 min @ 75 °F |
| Fast | 40–45 °F | shorter, but the cold gives it back |

Below ~35–40 °F epoxy **cannot cure at all** — it does not go slowly, it
stays soft forever. A cold laminate is not a slow laminate, it is a ruined
one. **Uses:** `TotalBoat 5:1 FAST hardener 6 oz, cold days`

### Dry-run the bag before you mix anything

Full rehearsal: cloth dry, caul in, bag sealed, pump on, gauge watched. Every
problem you find dry is free. Every one you find wet costs a laminate.

### The bag does not press the part onto the table

Envelope bagging puts the same pressure on every face of a closed body, so
the **net force is zero** — it consolidates from all sides and pushes the
part nowhere. The table only ever carries the board's weight. A blanket under
it is a nicety, not a requirement.

### What good looks like at de-bag

Even, dull peel-ply texture. No shiny patches (resin-rich), no white ones
(dry). Breather uniformly stained, not soaked in one corner.

---

# Appendix B — Machine envelope and workholding

Maker Shop runs an **Axiom AR8 Pro V5: 609.6 × 1209.8 × 149.9 mm.**

| | Needs | |
|---|---|---|
| Longer core half | 1030 × 560 | fits, 180 mm spare |
| Shorter core half | 370 × 560 | fits |
| Whole board in one piece | 1400 × 560 | **no** — hence the vertical seam |
| Glued 4-layer stack | 203.2 tall | **no** — hence the horizontal split |

**Y is the tight axis:** 560 mm in a 609.6 mm bed leaves 24.8 mm a side. Fine
for tape-down, no room for clamps.

**Two-sided registration** matters exactly once — only `Aft_Lower` flips.
Drill the dowel holes in the spoilboard and in the waste perimeter *before*
any 3D work starts.

---

# Appendix C — If the CNC falls through

The mast plate does not need a machine (step 7). For the core:

1. **Hot-wire the rocker and plan-shape, hand-shape the crown.** How every
   home-built board was made before CNC. Slow, forgiving in EPS.
2. **Job-shop just the core.** Send the STL; keep everything else in-house.
3. **Another makerspace or a maker with a large-format router.**
4. **Buy a shaped blank** and adapt the cavity by hand.

If it comes to this, flip **`HAND_SHAPE = True`** in `model/templates.py`
and it emits the full 21-template set again — outline, cavity, rim rebate,
both mast pockets, handle and leash pads. The check gauges (`CHECK_GAUGES`)
are the cheap end of the same family and come back with it. **Uses:**
`MDF 12 mm 4x8 sheet, three lid/ring guides`

---

# Risks, honestly

| Risk | Mitigation |
|---|---|
| **Shop bans EPS** | Ask before buying a pass. Appendix C |
| Shop will not run fibreglass on the CNC | Ask on the same call as the EPS one. Fallback: jigsaw the lid profiles to a line, and transfer-drill the holes off the ring |
| Never having run a CNC | Test piece in scrap first; foam is unbreakable |
| Flip registration wrong | Dowel pins; dry-run in air; check the mirror axis |
| Blank too tall for the gantry | Solved by sequence — 101.6 mm halves, bonded after |
| Running out of shop visits | Basic is 8/month, not unlimited; a day pass is $99 |
| Epoxy too cold to cure | Fast hardener + hot box; below 35 °F do not start |
| Crushing the core in the bag | Regulator at 5–10 inHg. Never "as much as it pulls" |
| Cavity cures with voids | The caul, not the bag. Wax and PVA it |
| Seam misalignment | Both halves off the same fixture and datum |

---

# Appendix D — Wiring

Grounded in what V1 actually ran, which is written up in
[efoil-2-electrical.md](v1/efoil-2-electrical.md). Three things in an earlier
draft of this appendix were wrong and are corrected below: the fuse is on the
**negative**, the positive **never touches the BMS**, and the charge port is
**already dead when the BMS is off** — no BMS change needed.

## The rule everything follows from

**A common-port BMS switches the NEGATIVE rail only. Pack positive is a
straight pass-through that never enters the BMS.**

**Confirmed against DALY's own wiring diagram** for this unit, which settles
three things that were open:

| Question | Answer from the diagram |
|---|---|
| Is there a B+ terminal? | **No.** The board has exactly two power terminals, **B−** and **P−**. Pack positive never lands on the BMS at all |
| Common or separate port? | **Common.** The load and the recharger both hang off the same **P+ / P−** pair |
| How is pack positive sensed? | Through the **sampling cable** — the same harness that taps each series junction |

So V1's JK and this DALY behave identically. Anything below that says "if
fitted" about a B+ terminal is now settled: there is none.

## The current path

V1's, with one change: V1 ran the charger and the ESC through the *same*
XT150 pair. V2 has a dedicated SP17 charge port, so each leg now branches.

```
   PACK +  ─── 8 AWG ───────► P+ ──┬── 8 AWG ──► ESC  V+
   (straight through,              │
    never enters the BMS)          └── 16 AWG ─► 10 A fuse ──► CHARGE  +

   PACK −  ─── 8 AWG ───────► B−  ─┐
                                    │  MOSFETs  (this is the switch)
                              P−  ◄─┘
                               │
                               ├── 8 AWG ──► ANL 150 A ──► ESC  V−
                               │
                               └── 16 AWG ─────────────────► CHARGE  −

   SAMPLING CABLE: taps every series junction AND the overall positive.
                   This is how the BMS sees pack + - there is no B+ wire.
   BUTTON:         2-wire to the BMS switch input - NOT in the main path
```

## Where the splits go — your question, answered

**You already own the splitter. It is P+ and P−.**

DALY's diagram draws both as terminal blocks with the load *and* the
recharger landing on them — that is the design intent, not an improvisation.
Everything meets there:

- **P+** — pack positive in, ESC positive out, charge positive out
- **P−** — from the MOSFETs, ESC negative out, charge negative out

**Fuse each leg for what it carries, rather than sharing one.** V1 shared a
single XT150 so both went through the 150 A ANL; with a dedicated charge port
there is no reason to, and a 150 A fuse never protected a 16 AWG lead anyway:

- **ANL 150 A** in the ESC negative, between **P−** and ESC V−
- **Inline 10 A** in the charge positive, off **P+**

### How to physically make the split

| | |
|---|---|
| **Stacked ring lugs on P+ / P−** *(recommended)* | 8 AWG under 16 AWG, star washer between. This is what the terminals are for — no new part, no new bay space |
| **2-post busbar** | Only if you want separately torqued, labelled landings. The bay is 75 mm deep, so it costs room you do not have much of |
| ~~Dual-barrel lug~~ | **No.** One barrel crimped onto 8 AWG *and* 16 AWG compresses neither properly. That is the joint that fails a year later |

## Joint by joint

| # | From | To | Wire | Termination |
|---|---|---|---|---|
| 1 | Pack + collector | **P+** | 8 AWG | ring lug, hydraulic crimp |
| 2 | **P+** | ESC V+ | 8 AWG | ring lug |
| 3 | **P+** | 10 A fuse → charge port + | 16 AWG | ring lug — stacks on joint 1/2 |
| 4 | Pack − collector | **B−** | 8 AWG | ring lug |
| 5 | **P−** | ANL fuse IN | 8 AWG | ring lug |
| 6 | ANL fuse OUT | ESC V− | 8 AWG | ring lug |
| 7 | **P−** | Charge port − | 16 AWG | ring lug — stacks on joint 5 |
| 8 | Sampling cable | 17 series taps + overall + | 22 AWG harness | as supplied — **this replaces any B+ wire** |
| 9 | BMS key-switch input | Panel button | 2 × 22 AWG | **JST GH 1.25 mm** at the BMS end |
| 10 | ESC phases | Motor, in the cavity | motor's own | 5.5 mm bullets + IP68 housing |

**On joint 8:** there is **no B+ power lead** on this BMS, and none is
missing. Pack positive reaches the board only through the sampling cable,
exactly as V1's JK did through balance wire #15. If you find yourself looking
for somewhere to land a pack-positive wire on the BMS, you are looking for a
terminal that does not exist — it goes to P+.

Every 8 AWG lug: **hydraulic crimp, then adhesive-lined heat shrink** over
the barrel and onto the insulation. Not soldered — solder wicks up the
strands and the stiff point it creates is where vibration breaks the wire.

## The charge port IS dead when the BMS is off

Correcting this appendix again, in your favour. Charge − returns through
`BMS P− → MOSFETs → B− → pack −`. **With the BMS off, those MOSFETs are open
and there is no return path**, so nothing can flow between the port's two
pins no matter what bridges them. You do not need a separate-port BMS, and
you do not need a switch in the charge leg.

What remains true, and worth knowing rather than worrying about:

- The **+ pin sits at pack potential** whenever cells are connected, because
  nothing switches the positive on any common-port design.
- **With the BMS ON**, bridging the two port pins *is* a short across the
  pack through the discharge FETs — same as shorting the ESC leads. Do not
  probe a live port with the BMS on.
- The port is inside the module, inside the cavity, under twelve M5s. It is
  not a bystander hazard; it is a you-with-a-multimeter hazard.

## Two mistakes that kill a BMS

1. **Never connect the balance harness before the main leads.** Main first
   (B−, then B+ if fitted), balance last. Disconnect in reverse: **balance
   off first.** With balance plugged in and B− floating, pack current returns
   through 22 AWG balance wires and takes the BMS with it.
2. **Meter the balance harness before plugging it in.** B0 is pack
   most-negative, B16 most-positive. Against B0 you should read a clean
   ladder, ~3.6 V per step. One transposed pair is a dead BMS and possibly a
   dead group.

## There is only one switch, and it is the BMS

**Nothing is plugged or unplugged in normal use.** The ESC and the charge
port are both permanently wired to P+ / P−, and the BMS's MOSFETs gate the
negative for both at once. Turn the BMS off and load *and* charge die
together — there is no separate load switch and no need for one.

The panel button is **not** in the power path. It lands on the BMS's
low-current **switch terminal** — JK calls it that, and it is what V1 used —
and all it does is tell the board to turn its FETs on or off. It carries
milliamps. The 92 A goes through the MOSFETs, which is what they are for.

> ### ✔ The DALY does have a key switch input — confirmed
>
> The Amazon listing never mentions one, which is why this was open. **DALY's
> own documentation does:** *"The default function of the key switch is to
> activate the BMS; other logic functions can be customized."* So the button
> has somewhere to land, and the design stands.
>
> Three things that follow, worth knowing before you wire it:
>
> - **It is a JST GH 1.25 mm connector, not a screw terminal.** DALY sell a
>   ready-made key switch for about $5 that plugs into it. Our M12 panel
>   button is bare wires, so it needs a **JST GH 1.25 mm pigtail** to marry
>   the two — a part worth having before the module closes, because
>   crimping GH 1.25 by hand is unpleasant and it is a $6 problem now versus
>   opening a sealed module later.
> - **The behaviour is configurable in the app.** Default is "activate the
>   BMS". Another option is *control discharge MOS and sleep* — contacts
>   open, the BMS opens the discharge MOSFET and sleeps. Pick that one and
>   the button behaves like a power switch rather than a wake button.
> - **Bluetooth is the fallback, not the plan.** The app can switch the
>   charge and discharge MOSFETs directly, so a failed button never strands
>   you — but starting the board should not require getting a phone out with
>   wet hands, which is exactly why the physical button is in the design.
>
> *(Connector type and the $5 key switch are community-sourced; DALY's own
> page confirms the switch input but not the connector. Check what is in the
> box before ordering a pigtail.)*

> A note on the term: "switch input" means *the input on the BMS that a
> switch connects to*, not switching the input side of anything. Nothing on
> the pack side is ever switched.

**So there is no precharge problem in service — and this BMS confirms it in
writing.** Its listing names a **"Pre-charging function"** among the upgrades,
so the surge of the FETs closing into the ESC's input capacitors is
soft-started by the board itself. That closes the one question the BOM had
left open on this ("worth checking once: some smart DALYs carry precharge").
It does.

The classic arc comes from mating a connector across a live pack into
discharged capacitors, and here that connector does not exist at all.

The one moment it *is* a real connection is **assembly** — landing the B−
lead for the first time with the ESC already wired will charge the caps
through that joint. Connect **B− last**, and if you want it gentle, bridge it
through a resistor for a second first. One-time, at the bench, with the lid
off.

## Sanity checks before the lid goes on

- Pack voltage at the collectors: ~57.6 V nominal, 67.2 V full.
- Charge port polarity, metered, with the pack live and the BMS on.
- ANL 150 A is in the **negative** leg, between P− and the ESC.
- Inline 10 A is in the **charge positive**, off P+.
- Button goes to the BMS **switch terminal** — two thin wires, nothing else.
- Tug every crimp. One that moves is one that failed.
- Dielectric grease on every terminal, then leak-test again with the vent
  blanked before the cells go in for good.

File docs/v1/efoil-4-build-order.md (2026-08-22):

> **V1 reference — not the current design.** This describes the board that was
> built, or early planning that predates the model. V2 is generated from
> `model/blender_board.py`; where the two disagree, the model and the docs
> linked from the [README](../../README.md) are correct.

# eFoil Build — Build Order & 3D Printing (V9)

**Last updated:** August 7, 2026

---

## CURRENT STATUS (Aug 7, 2026)

**Build is complete. In shakedown testing.**

| Phase | Status |
|---|---|
| 1 — Battery | ✅ Complete. Pack welded, BMS commissioned, charged and validated. **2–6 mV cell spread** under load and at rest — excellent. Zero OCP events in the BMS log, ever. |
| 2 — 3D printing / enclosures | ✅ Complete. Both enclosures sealed and **proven dry through three flooded-cavity tests.** |
| 3 — Foam & shaping | ✅ Complete |
| 4 — Fiberglass & finish | ✅ Complete. Painted, gasket in, traction pad on. |
| 5 — Electronics & assembly | ✅ Complete. Foil mounted, wires routed, full electrical test passed. |
| Water testing | 🔄 In progress — 3 sessions, all leak paths found and repaired, power problem diagnosed and fixed |

**Outstanding:**
- ❗ **Reed switch kill system not installed.** Parts on hand. This is the one real safety gap. Required before any beginner rides the board.
- Confirm cavity is dry after the latest round of sealing
- First successful foiling session

**Key corrections vs. the original plan:**
- Cam latches and PETG strike plates **abandoned** — lid is bolt-down with 6× M5 hex-drive inserts
- Hatch lid fiberglass **skipped** — epoxy hot coat only, so the hot coat is the sole water barrier
- Mast bolt pattern discrepancy (165 vs 190 mm) **resolved by using the Gong plate itself as the drill template** — no measurement needed
- Motor mount rods cut to **~171 mm**, not the 155 mm estimate
- VESC current limits raised from 80 A to **180 A motor / 100 A battery** — the 80 A motor limit was why the board wouldn't foil

---

## Build Order

### Phase 1: Battery

**1a. Cell prep & layout**
- Test all cells with multimeter — record voltages, reject any outliers (<3.5V or >3.7V out of box, or >20mV spread from pack average)
- Mark + terminal of every cell with sharpie dot (prevents orientation errors during assembly)
- Assemble Heyiarbeit 22.3mm spacer brackets into 9×14 grid (two spacer layers — top and bottom — holding cells from both ends)
- Load cells into holders with correct serpentine orientation: Row 1 positive up, Row 2 positive DOWN (rotated 180°), Row 3 positive up, Row 4 positive down, etc. Verify every row before moving to welding.

**1b. Cut nickel strips**

From SUIDI 0.2mm × 10mm × 5m rolls (2 rolls), cut:
- **28 P-group strips:** 10mm × ~210mm each. One for each row face (14 rows × 2 faces). Label each strip by row and face (e.g., "R1-top", "R1-bot", "R2-top", etc.).
- **117 bridging strips:** 10mm × ~30mm each. These connect individual cells between adjacent rows. Cut extras — small pieces are easy to lose or misalign.
- **Total nickel used:** (28 × 210mm) + (117 × 30mm) = 5,880mm + 3,510mm = 9,390mm = ~9.4m. Two 5m rolls = 10m total, leaves ~0.6m for mistakes/spares.

**1c. Pre-solder the 26 edge bridging strips with 8AWG jumpers (bench work, no cells)**

Of the 117 bridging strips, 26 will get 8AWG copper jumpers soldered along them (the 2 edge strips at each of the 13 row boundaries). Do this on the bench before any welding:

- Cut 26 short pieces of 8AWG silicone wire, each ~30mm long
- For each of the 26 edge bridging strips: lay the 8AWG wire along the length of the bridging strip and solder it down with good flux and plenty of solder. Pre-tin both surfaces first.
- Pull-test each solder joint — it should be strong enough that you can pull the wire moderately without it breaking off
- Label these 26 reinforced bridging strips distinctly from the 91 plain bridging strips

Middle bridging strips (91 of them) are left as plain nickel, no jumpers needed.

**1d. Prepare Pack + and Pack − end collector strips**

The Pack + strip is the Row 1 top P-group strip. The Pack − strip is the Row 14 bottom P-group strip. Both need a full-length 8AWG bus wire soldered along their length for low-resistance pack terminals:

- Pack + strip: 10mm × ~250mm (slightly longer than standard P-group strip to leave tail for termination). Solder full-length 8AWG wire (~280mm, runs past each end) along the entire nickel strip.
- Pack − strip: Same — full-length 8AWG bus wire soldered along the entire Row 14 bottom P-group strip.
- Pull-test solder joints.

**1e. Spot weld bottom face — P-group strips first**

Flip the 9×14 cell assembly upside down. Now you're accessing what will become the pack bottom.

- For each row, lay the bottom P-group strip over the 9 cells of that row and spot weld it down. 2 weld spots per cell in a line down the center of the strip (18 welds per P-group strip × 14 rows = 252 welds)
- Welder settings for 0.2mm pure nickel: Pulse 1 = 5-7, Space = 10ms, Pulse 2 = 15-18, Delay = 1s. Test on scrap first. Increase pulse strength if welds pull off; decrease if strip discolors or burns through.
- Row 14 bottom P-group strip is the Pack − (already has 8AWG bus wire pre-soldered) — weld it normally, the bus wire doesn't affect the welding.

**1f. Spot weld bottom face — bridging strips (alternating boundaries)**

Only 6 of the 13 row boundaries have bridging strips on the bottom face: R2-R3, R4-R5, R6-R7, R8-R9, R10-R11, R12-R13.

For each of these 6 boundaries:
- Place 9 bridging strips between the two rows, one per cell pair. Each bridging strip spans from one cell terminal in Row N to the corresponding cell terminal in Row N+1.
- 2 of the 9 bridging strips (leftmost and rightmost) are the ones with 8AWG jumpers pre-soldered. Place those at the edges.
- The 7 middle bridging strips are plain nickel.
- Weld each bridging strip with 2 spot welds per cell — 2 welds on the Row N side, 2 on the Row N+1 side. 4 welds per bridging strip.
- 9 bridging strips × 6 boundaries × 4 welds = 216 welds for bottom bridging

**1g. Voltage test bottom face so far**
- At this point, the pack has Row 2-3, Row 4-5, etc. connected in series pairs on the bottom face
- Not a fully connected pack yet — top face strips still needed
- Do a sanity check with multimeter at a few random bridging strips — should read ~3.6V across any series junction (next cell's voltage)

**1h. Flip pack, spot weld top face — P-group strips**

Flip cell assembly back right-side up.

- Weld all 14 top P-group strips (same process as bottom: 2 welds per cell, 252 welds total)
- Row 1 top P-group strip is the Pack + (already has 8AWG bus wire pre-soldered)

**1i. Spot weld top face — bridging strips (alternating boundaries)**

7 row boundaries have bridging strips on the top face: R1-R2, R3-R4, R5-R6, R7-R8, R9-R10, R11-R12, R13-R14.

- 9 bridging strips per boundary × 7 boundaries = 63 bridging strips on top face
- Same process as bottom: 2 edge strips have 8AWG jumpers (pre-soldered), 7 middle strips are plain
- 4 welds per bridging strip × 63 strips = 252 welds for top bridging

**1j. Voltage test fully assembled pack**
- Full pack voltage (Pack + to Pack −) should read ~50V (14 cells × ~3.6V) before charging
- Verify each cell group voltage individually by probing across each series junction — should read ~3.6V across each junction
- If any junction reads 0V, inspect the 9 bridging strips at that junction for bad welds

**1k. Balance lead attachment**
- Solder JK BMS balance harness wires to each of the 15 measurement points (Pack −, then each P-group + through the pack in sequence, ending at Pack +)
- Each balance wire solders directly to the P-group strip of the corresponding row — use the end of the strip near an edge where there's solid nickel (not on a weld spot)
- Route wires neatly along one long edge of the pack for later connection to BMS

**1l. Pack wrapping**
- Apply Kapton tape over all nickel + solder on BOTH faces of pack (top and bottom), covering all weld spots and solder joints
- Apply heat shrink tubing (300mm flat width PVC) around entire pack — shrink with heat gun until tight
- Cut small slits in shrink wrap at one short end to expose Pack + and Pack − bus wire ends for XT150 pigtail attachment
- Cut slit near balance harness exit point

**1m. BMS mounting and wiring**
- Place BMS flat on top of shrink-wrapped pack, centered on long axis
- 4 small dabs of silicone sealant between BMS corners and pack top — cure 24hrs to hold BMS in position against vibration
- Connect 2× 8AWG wires from Pack − bus to BMS B− terminals (parallel)
- Connect 2× 8AWG wires from BMS P− terminals to 150A ANL fuse (parallel on BMS side, combined into single 8AWG after fuse)
- Connect balance harness to BMS balance connector
- Connect NTC temperature sensor from BMS to pack surface (taped to cell body mid-pack)

**1n. Terminal pigtails & bench test**
- Solder XT150 connectors to short (~150mm) pigtails exiting the pack
- Pack + → XT150 positive pigtail (direct, no BMS interaction)
- Fuse output → XT150 negative pigtail
- Configure BMS via Bluetooth app: 14S Li-ion, current limits, temperature cutoffs
- Bench test: full pack voltage measurement, verify BMS reports all 14 cell voltages correctly, test push-button on/off switching
- Full pack should read 50-58V depending on state of charge

**Weld count summary:**
- P-group welds: 252 (bottom) + 252 (top) = 504 welds
- Bridging strip welds: 216 (bottom) + 252 (top) = 468 welds
- **Total spot welds: ~972**
- Plus 26 solder joints (8AWG jumpers to edge bridging strips) + 2 full-length solder joints (Pack +/- bus wires) + 15 balance lead solders + BMS connections

Plan for ~6-8 hours of welding spread across 2 evenings to avoid fatigue.

### Phase 2: 3D Printing — Enclosures

**Prerequisite:** Battery pack must be built, wrapped, and measured BEFORE committing enclosure CAD to print. Current dimensions (247×415×110mm exterior) are placeholders — real pack + BMS stackup drives final numbers.

**Battery enclosure (4-piece L-corner print):**
1. Measure assembled + wrapped pack with BMS silicone-mounted on top. Record footprint and total height.
2. Update Onshape enclosure model with measured values. Preserve 4mm walls + 10×10mm external vertical ribs + 20-bolt perimeter pattern (6 per long side + 4 per short side, corners dedicated).
3. Verify midpoint wall joints land in rib gaps (each corner piece ends at a full vertical rib that pairs with matching rib on mating piece for epoxy bond).
4. Print ONE corner piece first as test article (0.6mm nozzle, 0.24mm layer, 4 walls, 15% gyroid, ~233g/piece, ~6-8hr/piece). Test: rib cleanness, heat-set insert fit in scrap hole, joint dry-fit with a second test print later.
5. If test piece good, print remaining 3 corner pieces. **Mix materials** — 2 corner pieces in OVERTURE PETG green, 2 in ASA (UV + temp + printability balance). ASA pieces need draft shield + brim + 105°C bed on open-frame A1.
6. Install M4 × 8mm brass heat-set inserts in rib holes (5.2mm × 10mm deep). Soldering iron 220-230°C, 3-5 sec per insert, sink until d1 flush, let cool 30 sec before removing iron. Practice on scrap first.
7. Bond 4 corner pieces with thickened epoxy (TotalBoat + Cab-O-Sil). Scuff rib bond faces + wall overlap zone with 120 grit, wipe IPA. Assemble as 2× L-shape first, cure overnight, then bond L-shapes into full rectangle. Check diagonals for square while epoxy still green.

**ESC enclosure (single-piece print):**
1. Print single piece on A1 bed (fits at ~184 × 134mm footprint).
2. Install M4 × 6mm heat-set inserts (smaller stock, 5.3mm × 8mm deep holes) in rib positions — 8-10 bolts around perimeter.
3. No joint bonding needed (monolithic print).

**Aluminum plates (top + bottom, both enclosures):**
- 4mm 6061, cut to exterior flange dimensions of assembled enclosure
- Top plate: 20 × M4 clearance holes (4.5mm) matching rib bolt pattern for battery enclosure; 8-10 M4 holes for ESC enclosure
- Bottom plate: no bolt holes (permanent bond)
- Source: SendCutSend with DXF export from Onshape, OR DIY cut with jigsaw + drill (plywood template for hole positions)
- Drill method for DIY: sandwich aluminum between two MDF/plywood pieces, drill through sandwich at low RPM with cutting oil

**TORRAMI neoprene gaskets (top lid seals, both enclosures):**
- Trace aluminum top lid outline onto 1/8" TORRAMI sheet
- Cut perimeter with box cutter
- Punch bolt clearance holes with UNCO 5mm hollow punch (M4 bolt = 4mm shank, 1mm undersize for compression seal around shank)
- No adhesive — gasket sits between aluminum lid and PETG flange top, compressed by bolt torque

**Supporting prints (unchanged):**
- Print hinge shims (PETG, sized to Pyntrax 6" strap hinge leaf) → print motor mount parts (PETG, 0.6mm nozzle) → print props (PETG, 0.4mm nozzle, 100% infill) → sand and epoxy coat props

**NO LONGER NEEDED:** ~~Cam latch strike plates for battery enclosure~~ (was originally planned with Gustav-style toggle latches — replaced by bolt-down design)

### Phase 3: Board — Foam & Shaping
Buy 2 sheets XPS foam from Lowe's (4 blanks, 3 needed + 1 spare) → pre-cut ALL three layers on flat workbench with utility knife and wood chisel (660×280mm cavity through-cut on all layers same width starting 300mm from tail, shallow 19mm recess in Layer 3 top face for hatch lid, shallow 19mm recess in Layer 1 bottom for plywood, reed switch pocket + 30mm wire channel in Layer 3 at 250mm from tail — all done while slabs are flat) → epoxy 3/4" plywood base plate into Layer 1 recess, flush with hull surface → epoxy plywood backing blocks (80×45×19mm offcuts) to Layer 3 recess ledge at 2 hinge locations on nose-side short edge → glue layers with Gorilla Glue (clamp/weight overnight) → factory foam edge = board width (600mm), cut nose and tail outlines from cardboard half-template (three-zone geometry: 200mm flat tail → R500 convex arc to full width over 400mm → 600mm parallel midsection → R845 concave arc from full width to 100mm flat nose over 600mm) → shape nose bevel (bottom surface rises 130mm over 600mm along a Rho 0.5 parabola, starting at 1000mm from tail) → shape edges in CAD order: (1) Chamfer 1: 40mm × 60° top perimeter chamfer, full top edge; (2) Fillet 1: R50 nose rails only; (3) Chamfer 2: 40mm × 60° at bottom of nose vertical face; (4) Fillet 2: R20 full top perimeter — bottom edges stay sharp 90° everywhere except Chamfer 2 → smooth entire board 80→120 grit → fill any foam dings with thickened epoxy

### Phase 4: Board — Fiberglass (No Vacuum Bag, One Layer at a Time)
Fillet all internal cavity corners with thickened epoxy → glass cavity interior (2 layers, water-bag pressure) → glass hatch recess area (3 layers for strength) → seal all internal surfaces → glass hull bottom (4 layers, one at a time, cure/sand between each) → glass deck top (4 layers, one at a time, overlapping cured bottom at rails) → drill mast bolt holes (6.5mm clearance, 90×165mm pattern centered at 400mm from tail) and wire pass-through from below using Gong top plate as template → fabricate hatch lid (3/4" ply + 3-4 layers glass each side; finish-sand underside contact ring 220 grit + neat epoxy hot coat) → install 2× Pyntrax strap hinges on nose-side short edge with shims → set 6× M5 hex-drive inserts in ledge blocking, drill 7/32" lid clearance holes off the installed inserts → hot coat → prime → paint lime green → clear coat → **install hatch gasket on ledge** (scuff ledge 220 grit, double IPA wipe, peel PSA liner, press Trim-Lok X2897BT into continuous loop starting at long-edge midpoint, bend around corners, CA dab on butt joint, silicone grease on top surface, **leave hatch open 72 hours for PSA to cure before first latching**) → install traction pad (two pieces split at the hatch seam, bolt-hole cutouts, pull-loop gap)

### Phase 5: Electronics & Assembly

**Enclosure install in board cavity:**
1. Install sealed battery enclosure on plywood base plate (forward section)
2. Install sealed ESC enclosure on plywood base plate (mid section, forward of mast bolts)
3. Route phase wires from ESC box through plywood wire hole
4. Assemble XT150 connections in CESFONJER IP68 housings (6 housings on hand: 2 battery + 3 phase + 1 spare)
5. Route reed switch wire through foam channel into ESC box
6. Install water alarm sensor low in cavity

**Bench test before mast install:**
7. Motor in bucket of water, run through VESC Tool setup
8. Verify BMS bluetooth app reports all 14 cell voltages correctly
9. Test push-button on/off from battery enclosure
10. Test remote pairing and ESC response

**Mast mount assembly:**
11. **RESOLVED:** the Gong plate arrives pre-drilled — use the plate itself as the drill template rather than measuring. Centre it on the board centreline at 400 mm from the tail, pilot one hole, drop a bolt to lock it, then drill the rest. Drill 1/4" (0.250") through glass + plywood — the 15/64" bit in the Ryobi set is effectively zero-clearance on an M6 shank and will fight you.
12. Trace Gong plate outline onto TORRAMI 1/8" neoprene sheet; mark 4 bolt holes + phase wire pass-through position
13. Cut gasket perimeter with box cutter; punch 4× bolt holes with UNCO 5mm hollow punch (undersized vs 6mm bolt shank for self-seal); cut phase wire pass-through to match Gong plate opening
14. Assemble Gong V2 foil (mast → fuselage → wings → stab per Gong instructions)
15. Mount motor to mast using jkoljo V2 mount (4 parts PETG, already printed)
16. Feed phase wires through hollow mast from top plate end down to motor end
17. Bolt foil to board: 4× Mywish M6 × 50mm button head stainless, up from below through Gong plate → TORRAMI neoprene gasket → hull fiberglass → plywood → cavity fiberglass → GDFYMI M6 × 20mm fender washer → M6 nyloc
18. **Torque 8-10 N·m per bolt, star pattern, two passes** (first pass 5 N·m, second pass 10 N·m) — use 1/4" drive torque wrench
19. No 4200 or dielectric grease anywhere at mast mount — neoprene gasket is the complete seal, fully removable for Prius transport

**Final assembly and ride:**
20. Connect all 5 CESFONJER IP68 housings (XT150 power + phase)
21. Seal hatch — Trim-Lok gasket **mitred at the corners** and RTV-bonded, strap hinges on nose edge with an empirically-shimmed spacer, 6× M5 bolts with fender washers
22. **Submersion test with the cavity sealed but EMPTY** (no battery, no ESC) before trusting any seal
23. Maiden voyage at Lucky Peak Reservoir

---

## 3D Printing Summary

| Part | Material | Nozzle | Layer Height | Infill | Wall Thickness | Qty |
|---|---|---|---|---|---|---|
| Battery enclosure (4-piece L-corner split) | PETG green + ASA mix | 0.6mm | 0.24mm | 15% gyroid | 4mm wall + 10×10mm external ribs | 4 pieces (~233g each, ~932g total) |
| ESC enclosure (single piece) | PETG green | 0.6mm | 0.24mm | 15% gyroid | 4mm wall + 10×10mm external ribs | 1 |
| Hinge shims | PETG green | 0.4mm | 0.2mm | 100% | — | as needed |
| Motor mount (4 parts) | PETG green | 0.6mm | 0.25mm | 5 perimeters, 40% | — | 1 set |
| Propellers | PETG green | 0.4mm | 0.12mm | 100% | — | 4-5 |

**Material notes:**
- OVERTURE PETG Grass Green — 1kg on hand (delivered Apr 14). Covers ESC enclosure + hinge shims + motor mount + props. Split usage with ASA for battery enclosure to avoid running out.
- ASA — near-full roll on hand. Better UV + temp resistance than PETG, marginally harder to print on open-frame A1 (needs draft shield + brim + 105°C bed for warp control). Use for 2 of the 4 battery enclosure corner pieces.
- Heat-set inserts: Ktehloy 400pc kit — use M4 × 8mm for battery enclosure (5.2mm × 10mm deep holes), M4 × 6mm for ESC enclosure (5.3mm × 8mm deep holes).
- Bolts: Mr. Pen 810pc kit — M4 × 16mm button heads for battery enclosure, M4 × 12mm button heads for ESC enclosure.

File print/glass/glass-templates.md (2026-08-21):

# Glass ply templates

Half patterns - **cut on a fold down the centreline**. Green is the
fold line where the cloth leaves the flat and starts down the rail;
red are the relief slits. Print the HTML at **100% / actual size**
and check the 50 mm square on every page before you cut anything.

## deck ply

| | |
|---|---|
| Developed length | 1478 mm |
| Cloth width needed | **935 mm** (half pattern 467 mm) |
| Lap past the other ply | 60 mm |
| Relief slits per side | 21 |
| Slit depth | to 10 mm short of the fold line |
| Tiled pages | 16 (Letter) |

Half-widths every 100 mm, if you would rather use a batten and a tape than tape 20 sheets together:

| from tail (mm) | fold line | outer edge |
|---|---|---|
| 0 | 36.3 | 129.0 |
| 178 | 135.6 | 365.9 |
| 278 | 164.4 | 413.3 |
| 378 | 181.6 | 439.2 |
| 478 | 192.3 | 454.4 |
| 578 | 198.4 | 463.0 |
| 678 | 201.2 | 466.8 |
| 778 | 201.4 | 467.1 |
| 878 | 198.0 | 461.4 |
| 978 | 190.7 | 447.1 |
| 1078 | 179.1 | 424.8 |
| 1178 | 162.7 | 391.1 |
| 1278 | 139.6 | 343.8 |
| 1378 | 105.6 | 274.9 |
| 1478 | 18.1 | 105.1 |

## bottom ply

| | |
|---|---|
| Developed length | 1428 mm |
| Cloth width needed | **1024 mm** (half pattern 512 mm) |
| Lap past the other ply | 60 mm |
| Relief slits per side | 21 |
| Slit depth | to 10 mm short of the fold line |
| Tiled pages | 18 (Letter) |

Half-widths every 100 mm, if you would rather use a batten and a tape than tape 20 sheets together:

| from tail (mm) | fold line | outer edge |
|---|---|---|
| 0 | 44.4 | 137.1 |
| 100 | 165.7 | 396.0 |
| 200 | 200.9 | 449.9 |
| 300 | 222.0 | 479.5 |
| 400 | 235.0 | 497.1 |
| 500 | 242.5 | 507.1 |
| 600 | 245.9 | 511.5 |
| 700 | 246.2 | 511.9 |
| 800 | 242.0 | 505.4 |
| 900 | 233.0 | 489.5 |
| 1001 | 218.9 | 464.6 |
| 1102 | 198.8 | 427.3 |
| 1204 | 170.6 | 374.9 |
| 1308 | 129.1 | 298.3 |
| 1428 | 22.2 | 109.2 |

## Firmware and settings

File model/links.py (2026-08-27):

"""item name -> (Amazon ASIN, price seen, listing title).

GENERATED - regenerate rather than hand-edit. Every entry is a real
listing that was opened and read, not a guess. bom.py turns the ASIN
into a link on the item name and reports any priced line that has no
entry here as "verified but NOT yet linked".
"""

LINKS = {
    "1/2 in O-flute up-spiral, foam roughing":
        ("B001J9I6D4", 66.05, "Freud 73-214 1/2in Dia O-Flute Up Spiral Bit 1/2in Shank"),
    "1/2 in ball nose, finishing pass":
        ("B00KZM3GSG", 41.95, "YONICO Carbide Ball Nose End Mill 1/2in Dia 1/2in Shank"),
    "1/4 in composite bit - lid profiles":
        ("B00IDEOSXU", 0, "Amana Tool 46094 CNC Solid Carbide Up-Spiral "
         "Router Bit for Composite/Fiberglass/Phenolic ZrN 1/4 Dia x 3/4 x "
         "1/4 Shank"),
    "1/2 in spiral, 3 in cutting length - cavity wall":
        ("B0BTY16K5P", 82.99, "SpeTool Compression Spiral Router Bit 1/2in Shank 3in Cutting Length"),
    "1/4 in torque wrench, 10-50 in-lb":
        ("B0D7PWP7YF", 25.97, "1/4in Drive Click Torque Wrench 10-50 IN-LB Dual-Direction"),
    "16 AWG silicone, 6 colours x 5 ft":
        ("B089CPH72F", 14.49, "16 AWG Stranded Silicone Wire Spool 5 ft Each 6 Colors"),
    "1708 biax, 50in x 10 yd roll":
        ("B07RJWHPKG", 79.95, "Fiberglass 1708 Biaxial Mat Cloth 50in x 360in 10 Yard"),
    "2 mm glass beads or shim wire, bond-line control":
        ("B0FVSHYP99", 7.19, "uxcell 2000Pcs 2mm Solid Round Clear Glass Beads"),
    "2.5 mm straight cutter, opening the seal groove":
        ("B0GWSZ2KV2", 7.99, "Straight Router Bit 1/8in Shank 2.5x22mm Carbide 2 Flute"),
    "21700 cell holder, 1x2 brick, 50 pk":
        ("B092PSRGZ6", 9.99, "Heyiarbeit 50Pcs 2 x Cell 21700 Battery Holder Bracket Cell Spacer"),
    "3M 4200 FC 3 oz tube, skim over the bung":
        ("B00MJ9K78A", 17.99, "3M 05260 Marine Adhesive/Sealant Fast Cure 4200 3 Fl Oz"),
    "3M 60923 organic vapour / acid gas P100, pair":
        ("B00AEFCKKY", 17.99, "3M P100 Respirator Cartridge/Filter 60923, NIOSH Approved, 1 Pair"),
    "3M Fastbond 1077 water-based, CNC hold-down":
        ("B0GRSV587N", 26.02, "3M Fastbond Water-Base Multipurpose Adhesive 1077 Low VOC 8.2 oz"),
    "5.5 mm gold bullets, 20 pair":
        ("B096DJKR5Y", 12.99, "20 Pairs Gold-Plated 5.5MM Bullet Male and Female Connectors"),
    "5052 1/8in x 12 x 24, 2-pack - module floors":
        ("B0D3TH4TTC", 61.99, "2 Pack 5052 Aluminum Sheet Metal 1/8in x 12in x 24in"),
    "6061-T651 1/2in x 12 x 18 - mast plates":
        ("https://www.speedymetals.com/pc-2411-8360-12-6061-t651-aluminum-plate.aspx", 88.92, "1/2in 6061-T651 Aluminum Plate 12in x 18in"),
    "8 AWG marine ring lugs, 20 pk":
        ("B0CWGXB4NB", 9.99, "haisstronica 20PCS Battery Cable Lug and Heat Shrink Kit 8 AWG M6"),
    "8 AWG silicone, 10 ft red + 10 ft black":
        ("B0BYJRDT19", 21.99, "8 AWG Silicone Wire 10 ft Red and 10 ft Black"),
    "ANL 150 A fuse + holder":
        ("B0B6ZHJR7D", 9.99, "BOJACK 0/2/4 Gauge ANL Fuse Holder with 150 Amp Fuse"),
    "ASA filament, printed module shell":
        ("B09DKPYYBP", 24.49, "Polymaker ASA Filament 1.75mm Black 1KG UV Resistant"),
    "ASA filament, printed rim ring":
        ("B09DKPYYBP", 24.49, "Polymaker ASA Filament 1.75mm Black 1KG"),
    "Acetone, solvent-welding the printed joints":
        ("https://www.homedepot.com/p/Klean-Strip-1-qt-Acetone-Thins-Fiberglass-Resins-Epoxy-and-Adhesives-QAC18/100144922", 11.48, "Klean-Strip 1 qt Acetone Thins Fiberglass Resins Epoxy and Adhesives"),
    "Adhesive-lined heat shrink 3:1, 400 pc kit":
        ("B0BVVMCY86", 13.99, "400Pcs Heat Shrink Tubing Kit 3:1 Adhesive Lined"),
    "Adjustable hand sanding block":
        ("B0D4LNDYXD", 15.99, "Adjustable Hand Sanding File Block with Hook and Loop"),
    "BAK N21700CG-50 singles, spares":
        ("https://batteryhookup.com/products/new-3-6v-5000mah-bak-n21700cg-50-2170-lithium-ion-cells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", 2.50, "New 3.6v 5000mAh BAK N21700CG-50 2170 Cells - Single Cell"),
    "BAK N21700CG-50, 130-cell case (BatteryHookup)":
        ("https://batteryhookup.com/products/new-3-6v-5000mah-bak-n21700cg-50-2170-lithium-ion-cells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", 260.00, "New 3.6v 5000mAh BAK N21700CG-50 2170 Cells - Full Case (130)"),
    "Bag connector w/ ball valve, 1/4 in QD":
        ("B0FSKGGL8H", 19.59, "Vacuum Bag Connector with Ball Valve 1/4in Quick Release"),
    "Breather / bleeder cloth":
        ("B015NM0B8K", 13.95, "Breather Bleeder Cloth 1 Yard Elite Lab Vacuum Bagging"),
    "Cable ties, lacing, adhesive mounts":
        ("B08RMS5H25", 9.99, "140 Pack 3/4in Zip Tie Adhesive Mounts with Ties"),
    "Compression flush-trim bit, 1/4 in shank, lid masters":
        ("B0GDDXH1YH", 21.99, "SHARPRO Compression Flush Trim Router Bit 1/4 Inch Shank, Bottom Bearing, 1-1/4 in CL, 3 in OVL"),
    "Ryobi ONE+ P601 trim router, tool only":
        ("https://www.homedepot.com/p/RYOBI-ONE-18V-Cordless-Fixed-Base-Trim-Router-Tool-Only-with-Tool-Free-Depth-Adjustment-P601/206955202", 69.00, "RYOBI ONE+ 18V Cordless Fixed Base Trim Router, tool only"),
    "Black epoxy pigment, marking the lid plugs":
        ("B09NYDCXBQ", 8.99, "HTVRONT Black Epoxy Pigment Paste, 1.76oz/50ml, "
         "Higher Concentrated, For Resin Coloring"),
    "Black wax filler sticks, blocking + marking the bolt holes":
        ("B0CCDL8XNV", 7.99, "SEISSO Furniture Repair Crayon, 6 PCS Wood "
         "Filler Sticks, Scratch Repair Wax, Black"),
    "Charger 67.2 V 5 A, 16S  (NOT 58.8 V)":
        ("B0DK6FTB1P", 45.99, "67.2V 5A Fast Charger for 16S 60V Li-ion, C13 3-Pin IEC"),
    "Chip brushes 2 in, 36 pk":
        ("B078XJ2DCJ", 17.99, "Pro Grade 2in Chip Brushes Disposable 36 Pack"),
    "Coiled ankle leash":
        ("B096VL3DHV", 14.99, "Coiled SUP Leash Premium Paddle Board Ankle Leash"),
    "Leash plug 30 x 12.5, stainless pin, 2 pk":
        ("B0C6XLK8L9", 6.99, "E-outstanding Surf Leash Plug 2PCS 30x12.5mm "
                             "Surfboard Longboard Leash Plug Round Board Cup"),
    "DALY Smart BMS Li-ion 16S 60V 150A":
        ("https://www.amazon.com/dp/B0CXXFQT9S", 147.70, "DALY Smart BMS 16S 60V 150A Li-ion WiFi Bluetooth CAN RS485"),
    "Dielectric grease, terminals":
        ("B0D6R543V2", 8.99, "BTAS Dielectric Grease for Electrical Connectors 1oz"),
    "Divinycell H-100 1/4in quarter 21x42, hatch lid cores - 2 sheets bonded to 1/2in":
        ("https://fiberglasssupply.com/1-4-in-h-100-divinycell-quarter-sheet-21-x-42/", 49.59, "1/4 in H-100 Divinycell Quarter Sheet 21in x 42in (L20-1894)"),
    "Divinycell H-80 1/4in quarter 24x48, module lid cores":
        ("https://fiberglasssupply.com/quarter-sheet-1-4-h-80-divinycell-plain-sheet/", 53.94, "Quarter Sheet 1/4in H-80 Divinycell Plain Sheet (L18-1070)"),
    "Divinycell H-80 3/4in quarter sheet 24x48, mast block + leash pad":
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

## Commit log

2026-08-17 eFoil V2: parametric board model, CNC drawings, templates and BOM
    Everything for the second board is generated from model/blender_board.py -
    hull, cavity, G10 rim, sandwich lid, mast hardpoint, module, conduit and
    handles - so the drawings, the cut list and the costs cannot drift from the
    design. Every run re-checks fit, clearance and the structural margins and
    prints FAILS if any of them break.
    model/ the parametric model and the tools that read it
    cnc/ per-part DXF + cut list, and the 14 MDF templates
    docs/ BOM, fabrication plan, colour key, V1 as-built notes
    print/glass/ developed glass ply patterns
    Generated output (renders, .blend, .stl) is git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
    [01_rim_ring.dxf, 01a_ring_bar_long.dxf, 01b_ring_bar_short.dxf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]
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2026-08-21 Module: printed ASA shell replaces the bonded G10 box
    G10 walls were specced on "G10 saves weight" and that is false wall-by-
    wall: 3.175 mm G10 walls + a bonded flange ring + 4 corner posts came to
    1323 g against ~1130 g printed, and cost six CNC parts, a bond jig, a
    four-joint tolerance chain and a groove routed after assembly. The
    module's real win over V1 is one box instead of two and a sandwich lid
    instead of 4 mm alu - neither needs G10 walls.
    - shell prints in 4 L-pieces split at wall midpoints (corners come out
    solid); paired 10x10 seam ribs self-align and double the bond area
    - flange prints integral, M4 heat-set inserts back on their proper
    material - this line went heat-set (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
    [01_rim_ring.dxf, 01a_ring_bar_long.dxf, 01b_ring_bar_short.dxf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]
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2026-08-21 Rim ring goes printed ASA with captive nuts - no G10 left on the board
    Derek pushed back on three of my four objections and was right on all
    three, so I checked them properly instead of defending them:
    - GROOVE: "printed grooves hold +/-0.2" is true of a groove on a
    vertically printed wall. This ring prints FLAT, so groove depth is
    layer count - 2.4 = 12 layers, ~0.05 repeatable. That is TIGHTER than
    hand-routing G10 on a finished board, which was the operation this
    design was most afraid of. Template 14 deleted with it.
    - BOND: epoxy really does not grip ASA, and it does not matter - the
    ring is bedded in 4200 (polyurethane, which does, per V1) and then
    glassed over with the who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
    [01_rim_ring.dxf, 01a_ring_bar_long.dxf, 01b_ring_bar_short.dxf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]
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2026-08-21 Floor-to-wall joint redesigned for aluminium; bore the 18 lid inserts
    INSERT BORES. The 18 module lid heat-set inserts were drawn as studs
    standing in solid ASA with NO HOLE under any of them - the same bug the
    mast bushings had, and it survives every clearance check because a stud
    that is inside the part never collides with anything. Cut on the
    assembled shell before it splits, so each bore lands in whichever piece
    owns that bolt. 969 mm3 of interference in one piece alone -> 0.0.
    Audited the rest while I was there: leash, mast plate, rail strips,
    handle pads, port flange and hatch nuts all had their bores already.
    FLOOR JOINT. Both halves of it were decided when the floor was G10 and
    neit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
    [04_module_floor.dxf]
2026-08-21 Audit every script against the model; retire the one that had drifted
    Only cnc_drawings.py derived from blender_board.py. templates.py and
    glass_templates.py go through it, so those were live too - but the rest
    each held their own copy of the numbers, and nothing failed when the
    model changed. They just quietly reported last month's board.
    DELETED fleet_cost.py. It was a second, parallel cost model duplicating
    bom.py, and it had drifted a long way: an H-200 mast block (never used),
    a DALY 200 A (we buy 150), a $629 foil (it is $818), and three sheets of
    G10 (there are none). Its G10 sheet/nesting machinery was already
    vestigial - bom.py stopped calling it when the last G10 part went. Only
    t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
    [T01_planform_half.dxf, T02_cavity_opening.dxf, T03_rim_rebate.dxf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]
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2026-08-22 Templates 21 -> 4: the router set was the hand-shaping fallback
    Derek is right. Every BEARING template is a router guide for a feature
    the CNC cuts anyway - outline, cavity, rim rebate, both mast pockets,
    handle pad, leash pad. With a month pass booked they are dead weight.
    They only ever existed as the hand-shaping fallback, and that is now
    stated rather than implied: templates.py gates them behind
    HAND_SHAPE=False, and flipping it to True emits all 21 again if the
    machine falls through.
    What still emits is four GAUGES - three station sections and the
    rocker/deck profile - because a few sections are worth having to check a
    machined core before it gets glassed. Thirteen was hand-shaping den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
    [T01_planform_half.dxf, T02_cavity_opening.dxf, T03_rim_rebate.dxf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]
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2026-08-22 bom: link every Amazon line to a real listing, and fix fastener pricing
    105 lines now carry the ASIN of a listing that was actually opened and
    read. Item names render as links in both bom.md and shopping.md, so
    ordering is clicking through a list rather than re-searching everything.
    Links live in a generated model/links.py (item -> ASIN, price, title)
    rather than as an argument on 100+ add() calls, so re-checking prices is
    a diff of one file. bom.py now treats THE LISTING AS THE PRICE: where a
    line is linked, the listing's price overrides the literal, and every
    disagreement is collected and printed at the end of the build so an
    override is never silent. 45 lines repriced, net only +$52.91 -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
    [links.py]
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2026-08-22 bom: source the battery pack, and let the link decide the vendor
    DALY BMS found on Amazon at $147.70 against the $159.00 carried, sold by
    the official DALY store, and confirmed Li-ion rather than LiFePO4 - a
    16S LiFePO4 BMS is a different pack voltage and would have been the easy
    wrong answer. Saves $22.60 across two boards and removes Battery
    International as a vendor entirely.
    BAK cells stay at Battery Hookup, both variants off the same product
    page, both exactly the price already carried. They are NOT available on
    Amazon - loose lithium cells are restricted there - so that is a checked
    fact now rather than an assumption.
    Also made vendor assignment follow the LINK. gen_links.py now emit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
    [links.py]
2026-08-22 bom: every purchasable line now links to a real listing (0 unsourced)
    Five parallel agents sourced the remaining 18 lines. 126 of 129 lines
    link to a page that was opened and read; the 3 that do not are sales tax
    and two freight allowances, which have no product page by definition.
    TWO CORRECTIONS TO MY OWN EARLIER CLAIMS:
    - THE VR20 IS AN EASY COMPOSITES PART, NOT FIBRE GLAST. It sat under
    Fibre Glast for this whole project. fibreglast.com returns ZERO results
    for "VR20" - their part numbers are numeric. It is easycomposites.us,
    $52.00, 30 in stock. Fibre Glast's nearest equivalent is the Bleedoff
    Valve Assembly 902-A at $70.97, and that is a manual needle valve: it
    bleeds vacuu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
    [links.py]
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2026-08-22 bom: full-deck EVA sheet, and delete the acetone gallon
    TRACTION: replaced the 3-piece surf pad with a full-deck self-adhesive
    EVA sheet, 2400 x 600 x 5.8 mm (0.23 in - about half a typical surf pad,
    since thin was the requirement). Derek's call and it suits a foil board:
    you move your feet fore and aft through the whole ride to trim, so a pad
    sized for a surf stance leaves you on bare paint half the time.
    One sheet per board covers a 1400 x 560 deck with ~1000 mm left over.
    The 47.2in-wide sheet would yield both decks side by side from one sheet
    at $123.48, but two of these are $108.28 AND leave far more usable
    offcut - cheaper and more useful. That offcut now feeds the EVA bedding
    pads in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
    [links.py]
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2026-08-22 pad: one piece not panels, slope-limited to the top, tapered, rounded lid
    Six corrections from Derek, all in the model and the cut pattern.
    NOT PANELLED. I proposed longitudinal strips because the deck arc runs
    ~8.6% longer than its flat projection and that excess varies along the
    board. The counter-argument is better: seams land in the middle of where
    you stand, and every seam is an edge that lifts and packs with grit. So
    one piece on the deck, one on the lid. The consequence is real and is
    now written into the cut note - with no seams to absorb the variation,
    the slack goes into stretch and into trimming AT THE RAIL, so cut long,
    trim on the board, and work from the centreline outward.
    O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
    [15_deck_pad_nest.dxf]
2026-08-22 pad: smooth edges, 3 pieces, no side slivers - and cut the machining split
    Four corrections from Derek.
    JAGGED EDGES had two causes, both real.
    - _deck_slope_edge STEPPED outboard in 2 mm samples and returned the last
    one that passed, quantising the entire pad outline to a 2 mm staircase.
    It now bisects to the angle. On a 5.8 mm sheet that staircase was not a
    rendering artefact, it was the cut line.
    - The pad was a grid with the hatch BLOCKED out cell by cell. A cell is
    either in or out and nothing interpolates the boundary, so every edge
    near the hatch came out stepped at the cell pitch. There are no holes
    any more - each piece is bounded only by a smooth half-width function.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
    [15_deck_pad_nest.dxf]
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2026-08-22 three build-order errors Derek caught, and the numbers behind each
    MAST PLATE IS A MACHINED PART. The cut list said "no longer a CNC part:
    a rectangle and four tapped holes is bandsaw and drill-press work". That
    reasoned from V1, where the holes were THROUGH holes with a nut on the
    far side and clearance absorbed every error of position, angle and depth.
    None of it transfers to blind tapped holes, where the thread IS the
    fastener and four bolts must start at once. The budget, computed and now
    in the report:
    radial slop in Gong's clearance hole 0.50 mm
    true position the pattern must hold 0.25 mm (errors add, not cancel)
    wander from a hole just 2 deg off 0.35 mm <-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
    [efoil_v2.blend]
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2026-08-22 wiring: there is no busbar, and the charge port can be made dead
    TWO CORRECTIONS, both Derek's.
    THERE IS NO BUSBAR. I wrote a whole topology around "the P+ busbar" and
    then justified it with the BOM line `M6 stainless stud/busbar hardware` -
    a $14 line with NO note, never specified, no space budgeted, and matched
    to a distribution block by an agent's guess that was flagged as a guess
    at the time. Nothing was designed around it. I asserted "that is what the
    M6 distribution block in the BOM was always for"; it was not.
    The positive node is the ANL FUSE HOLDER'S INPUT STUD, which already
    exists inside the module. Pack B+, charge +, and the BMS sense lead
    ring-lug onto it - three lugs, one stu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
    [efoil_v2.blend]
2026-08-22 wiring: rewrite Appendix D from V1's real topology - I had it wrong 3 ways
    Derek pushed back and he was right. Went and read what V1 actually ran
    (docs/v1/efoil-2-electrical.md) instead of reasoning from first
    principles, and three things I wrote were wrong:
    1. THE FUSE IS IN THE NEGATIVE LEG, not the positive, and it sits
    DOWNSTREAM of the BMS - Pack- -> BMS B- -> MOSFETs -> P- -> ANL ->
    ESC-. I had written "the fuse goes at the source, on the positive"
    as though it were a rule. It is a convention for chassis-ground
    vehicles; this pack floats, and V1 fused the negative.
    2. THE POSITIVE NEVER TOUCHES THE BMS. Pack + is a straight pass-through
    to the ESC. I had it running thr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
    [efoil_v2.blend]
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2026-08-22 model the cell holders - and correct my own assumption about them
    The holders are in the model now: two perforated plates, one at each end
    of the cells, 128 bores each, in the Electrical collection.
    I HAD THE PART WRONG BEFORE MODELLING IT. My first assumption was cradle
    spacers that the cell sits INTO, which would add height per end and
    cascade through pack_h -> module -> cavity -> board thickness. That is
    not what these are. 1x2 spacer bricks are THROUGH-HOLE: the cell passes
    through and the brick locates it sideways. So they add NO height, nothing
    cascades, and pack_h stays exactly where it was. Modelling it is what
    made that obvious - I was about to grow the board by 8 mm for no reason.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
    [efoil_v2.blend]
2026-08-22 open up the pack-to-flange clearance 2 -> 5 mm, and unbury the terminals
    PACK UNDER THE FLANGE WAS 2 mm. Derek called it, and it does not survive
    contact with the parts: ASA runs about +/-0.3 on a good day and more once
    a 400 mm printed flange has warped a little, 21700s vary roughly +/-0.2
    in length, and a spot weld leaves a bump on top of that. Any two of those
    eat the whole gap - and this is the clearance a 14 kg pack has to SLIDE
    SIDEWAYS through during assembly, not a static fit.
    Now 5 mm. Costs 3 mm of board thickness, 156.8 -> 159.8, and nothing
    else: no check fails, the ledge still clears the rail at 5.8 mm, the rim
    filler still fits the print bed at 5.3 mm of margin, and the blank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
    [15_deck_pad_nest.dxf, efoil_v2.blend]
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2026-08-23 links.py kept selling three parts the build had already dropped
    Deleting a line from bom.py never deleted its listing. Three dead entries
    were still sitting in links.py fully sourced and priced: the kayak carry
    handle that lost to the grab handle, the 3-piece traction pad the full-deck
    EVA sheet replaced, and a nose-cone fastener line under its OLD name.
    That last one was the dangerous one. It carried the $13.98 kit price, so the
    day anyone renamed the $0 "off the kit I already bought" line back to
    matching it, add() would have silently repriced it and charged for the same
    kit twice. Orphans are not clutter, they are ambush.
    build() now refuses to finish while LINKS or LINK_VENDOR names an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
    [links.py]
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2026-08-23 the module handle: the model said webbing, the BOM said bought, nobody bought the bolts
    The geometry was already right - MOD_HANDLE builds flat pads with two threaded
    holes, no slot, nothing to thread a strap through. Only the words were still
    describing a webbing loop: the constants, the build comments, and both report
    strings. They now say what the part is, which is the same bought kayak grab
    handle that goes on the rails.
    Chasing that turned up two things the prose was covering for.
    M6 heat-set insert, strap mounts - $9.99 for an insert nothing takes. The rail
    strip is 12.7 mm of 6061 and the model taps M6 straight into it; a heat-set
    insert melts into plastic and there is no plastic th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
    [efoil_v2.blend]
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2026-08-23 turn the module flange outward - 9.5 mm of board that bought nothing
    Derek's call, and it is the one change that frees the height the pack was
    spending on an assembly move. With nothing overhanging inboard the pack is
    simply lowered in, so int_h stops needing pack + flange + clearance and needs
    only pack + clearance. 164.9 -> 155.4 mm.
    IT COST NO WIDTH, which is why it works where the last attempt did not. The
    module already carries 10 mm seam ribs proud of its walls and the cavity
    already clears them, so a flange living in that same gap is free. The rim
    ledge sits at 5.8 mm off the deck edge either way - unchanged. Turning the
    pack sideways instead needed 21 mm the board did not have.
    It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
    [01_rim_ring.dxf, 02_hatch_lid.dxf, 03_hatch_lid_core.dxf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]
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2026-08-23 the mast gasket's job moved to the conduit bore - record why
    Derek: V1 had a gasket under the mast plate for waterproofing; V2 seals the
    hole the wires actually run up instead. That is already what step 18 does -
    EPDM bungs in the O32 bore, punched for the leads, filleted over with 4200 -
    but nothing said it REPLACED the V1 gasket, so "no gasket here" read as an
    omission rather than a decision. Step 23 says it now, and points at the step
    that carries the job.
    Punch set is on-hand, not bought - Derek has punches. NOT LINKED, and that
    matters: a listing price overrides the literal, so leaving the link on a $0
    on-hand line would have repriced it to $17.99 and quietly billed for a tool
    already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
    [links.py]
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2026-08-23 the handle span was set by the board; a strap does not care what the board wants
    Derek: "we need to redesign the handles to fit the span of actual handles i
    can get." He is right, and the model said so in as many words - "THE MODEL
    SETS THE HOLE PATTERN, NOT THE HANDLE ... the handle gets drilled to suit."
    That works for the hole SPACING. It does not work for the SPAN, because a
    strap is a fixed length. Whatever is left over between its ends and the bolts
    has nowhere to go but up, as the arch your fingers pass through:
    L = S + 8h^2 / 3S
    and that is arithmetic, not preference. 110 mm centres with a 25 mm arch
    implies a 125 mm strap - shorter than anything sold. Derek's handle is 7 in.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
    [01c_handle_strip.dxf, efoil_v2.blend]
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2026-08-23 the module does not have to fit UNDER the rim ring - 155.4 to 142.2 mm
    Derek: "there is 31 mm between the top of the module and the bottom of the
    main lid, that space could be shrunk so the top of the module lid sits
    halfway up the rim ring."
    He is right and I had been answering the wrong question. I kept auditing the
    gap between the module and the cavity CEILING - already down to 3 mm - and
    reporting the ring and the hatch lid as structure that had to sit on top of
    it. But the ring is a PICTURE FRAME. Its inner opening IS the cavity,
    518 x 323, and the module's widest part is its flange at 457 x 314. It passes
    straight through. Nothing said the module had to stop underneath it.
    So cav_dep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
    [15_deck_pad_nest.dxf, efoil_v2.blend]
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2026-08-23 the cells were drawn 7.3 mm too tall, and the module floor rode the fillet
    Two things Derek spotted in the model, both real, and the first one was not
    the bug I thought I had already fixed.
    THE BRACKET WAS ALWAYS FLUSH. CellHolder_Top tops out at 103.2 and the cell
    top is 103.2 - correct since the datum fix. What was wrong is the CELLS:
    _tube() drew them from iz0 to iz0 + pack_h, and pack_h is CELL_H +
    PACK_TERM_H. Every cell body was drawn 7.3 mm too tall - the height of the
    nickel and Kapton that goes ON them, not of the cell. So the bracket looked
    low while sitting exactly where it belongs. Drawn to CELL_H now, and
    PACK_TERM_H gets its own object rather than being an undrawn void between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
    [04_module_floor.dxf, efoil_v2.blend]
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2026-08-23 draw the strap, and it immediately fouled the wire bay
    Derek: the module handle holes do not look 7 inches apart. They are not, and
    they are not meant to be - the same 178 mm strap arches over whatever span it
    is given. But the model drew two pads and NOTHING BETWEEN THEM, so there was
    no way to see that from the geometry, and no way for a check to reach it.
    Drawn as the parabola it actually forms, it failed on the first build:
    12 mm of pad + 53.2 mm of arch = 65.2, in a 68 mm wire bay
    2.8 mm of daylight behind a strap you have to get a hand through. The span
    cannot move to fix it either - the conduit sits 5 mm inboard of those pads
    and the gland row 5.5 mm outboard.
    SO THE WIRE BAY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
    [01_rim_ring.dxf, 02_hatch_lid.dxf, 03_hatch_lid_core.dxf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]
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2026-08-23 shrink the module's ends, and the vent was sitting on the handle pad
    Derek: the aft and fwd gaps should shrink; and the air vent lands right on
    the handle hardpoint; and draw the rail handles too.
    PACK_END_CLR WAS 14.7 FOR CORNER POSTS THAT DO NOT EXIST. The comment said
    "was CORNER_POST + 2" and nothing named Post is built any more - the shell
    went to four L-pieces with dovetails and ribs, and the posts went with it,
    but the clearance they set stayed behind. Two interference pairs still named
    them, which is worse than useless: a check on a part that is never built
    passes for the wrong reason.
    Measured both ends before touching it. The nearest thing to either interior
    face is the flange, 1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
    [01_rim_ring.dxf, 02_hatch_lid.dxf, 03_hatch_lid_core.dxf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]
2026-08-23 round the module's corners - the wall thickness picks the radius, not taste
    Derek: those corners can be sharp, and glassing a lid over a square one will
    not work. Both true, and the second is the rule the cavity fillet already
    obeys - laminate will not turn tighter than GLASS_R without bridging, which
    is exactly why CAV_FILLET_R is what it is.
    THE RADIUS IS A WALL NUMBER. The wall's outer corner rounds while its inner
    stays square, so the wall thins on the diagonal by R - (R-ENC_WALL)*sqrt(2):
    3.17 mm of the 4 at R6, 2.34 at R8, 1.51 at R10, 0.69 at R12. Rounding the
    INNER corner too would hold it at a full 4, and it cannot be done - an inner
    radius of R-4 eats the corner the pack sits in,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
    [efoil_v2.blend]
2026-08-23 the seal and the bolt circle never got the memo about the corners
    Derek spotted it: rounding the module's profile left the gasket and the lid
    bolts on the old square outline.
    THE BOLTS. bolt_ring has taken a corner radius since the HATCH lid hit this
    exact problem - its docstring still says "placing them on a plain rectangle
    put the four corner bolts outside the lid's rounded corners" - and the module
    was still calling it with a bare rectangle after its own corners were
    rounded. The corner bolts were not off the part, but they had 2.15 mm of
    edge material where every straight run has 6.5. Passing the radius puts them
    on the arc, where the edge distance is 6.5 by construction.
    THE GASKET wa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
    [efoil_v2.blend]
2026-08-23 Wire bung: spread the leads, shrink the bore, squeeze it with the plate
    The three phase leads leave the mast touching in a line - an alu mast's
    internal cavity is only ~12-14 mm across, so 6.5 mm leads cannot lie any
    other way. Three touching jackets are three capillary paths. The bung's
    first job is spreading them, not sealing.
    Rolling the line into a triangle is also what let the bore shrink: three
    leads 2 mm apart span 23.5 mm in a line and 16.3 mm in a triangle, so
    CONDUIT_D drops 32 -> 26 and every conduit clearance improves with it
    (handle 5.0 -> 8.0 mm).
    - V2_WireBung: a O31.75 disc off the 1/2in 50A sheet already on the list,
    3 x O5.5 on a O9.8 triangle, 15% interference on the l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
    [12_mast_plate.dxf, efoil_v2.blend]
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2026-08-23 Hole alignment: the mating part is the master, not the drawing
    Derek: hand-fitting twelve lid holes to the printed ring is the day V1 lost.
    Every hole pattern on this board mates to something that was not machined
    from the same drawing - the hatch lid meets a ring printed in SIX pieces,
    dovetailed, welded and glassed into a rebate; the mast plate meets a Gong
    extrusion. Drilling either to nominal guarantees hand-fitting afterwards.
    The flush countersink I just added makes it WORSE, and that is the part
    worth noticing: a cap head over a clearance hole does not care where the
    hole is, but a flat head's cone centres itself, so twelve cones on a
    drifted pattern fight each other and the lid nev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
    [02_hatch_lid.dxf, efoil_v2.blend]
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
